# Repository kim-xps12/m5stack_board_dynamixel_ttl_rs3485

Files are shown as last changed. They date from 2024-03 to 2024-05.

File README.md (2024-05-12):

# DYNAMIXEL TTL interface board for M5Stack

## About
M5StackからDYNAMIXEL TTL対応のシリアルサーボを操作するためのオリジナル基板です．KiCAD 7で設計しました．

## Appearance

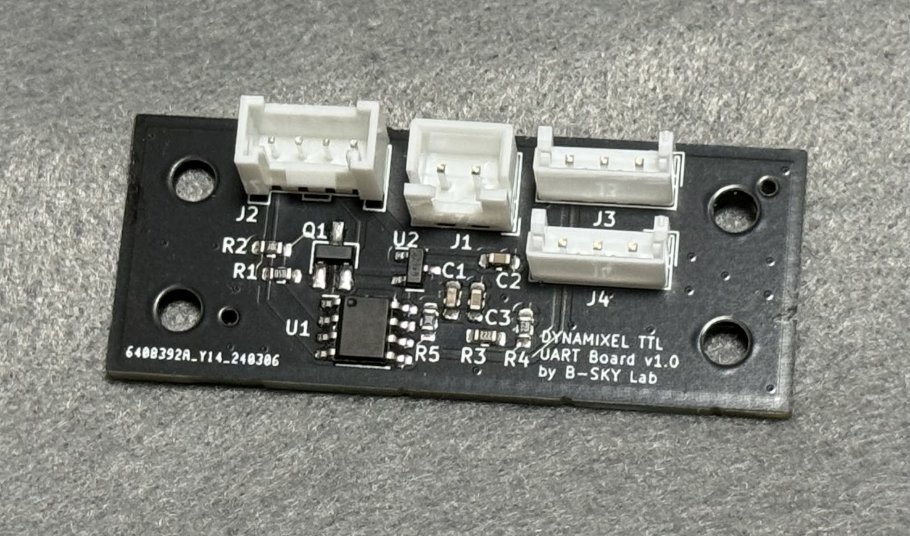
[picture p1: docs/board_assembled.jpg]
assembled board


## Usage

配線と動作の様子はこちら．

https://www.youtube.com/watch?v=RdcbOagrEI8

## Schematics

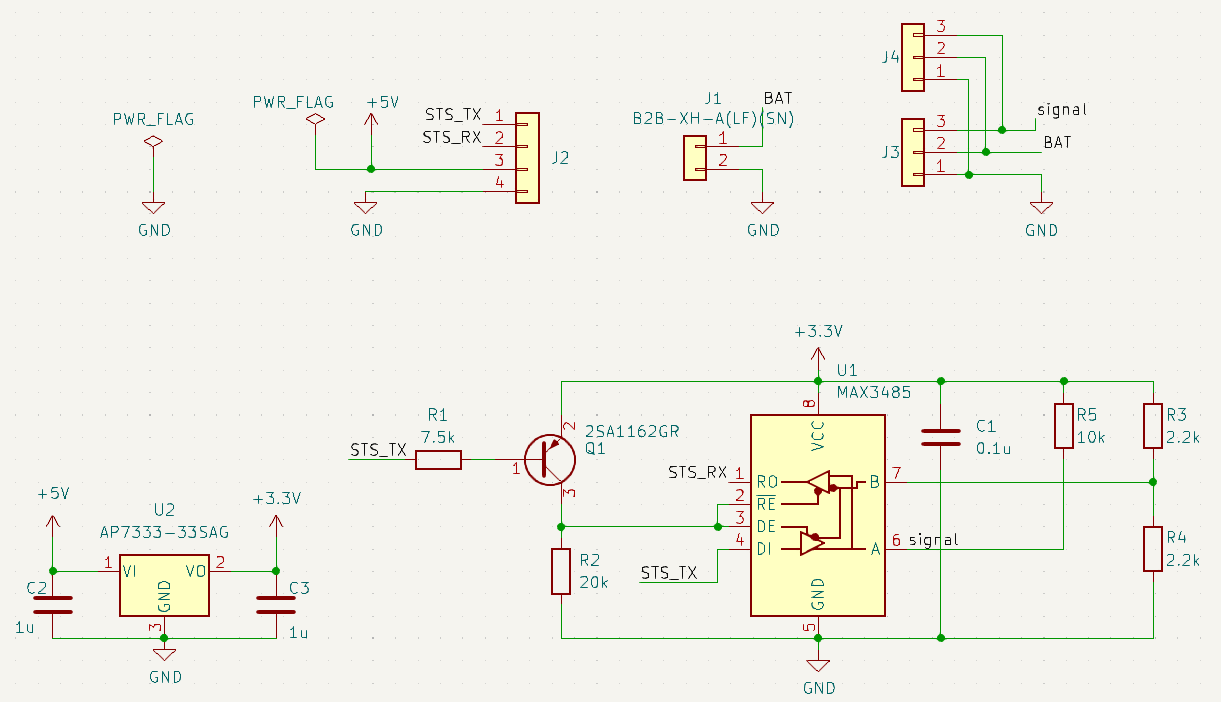
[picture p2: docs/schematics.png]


## Pin assign

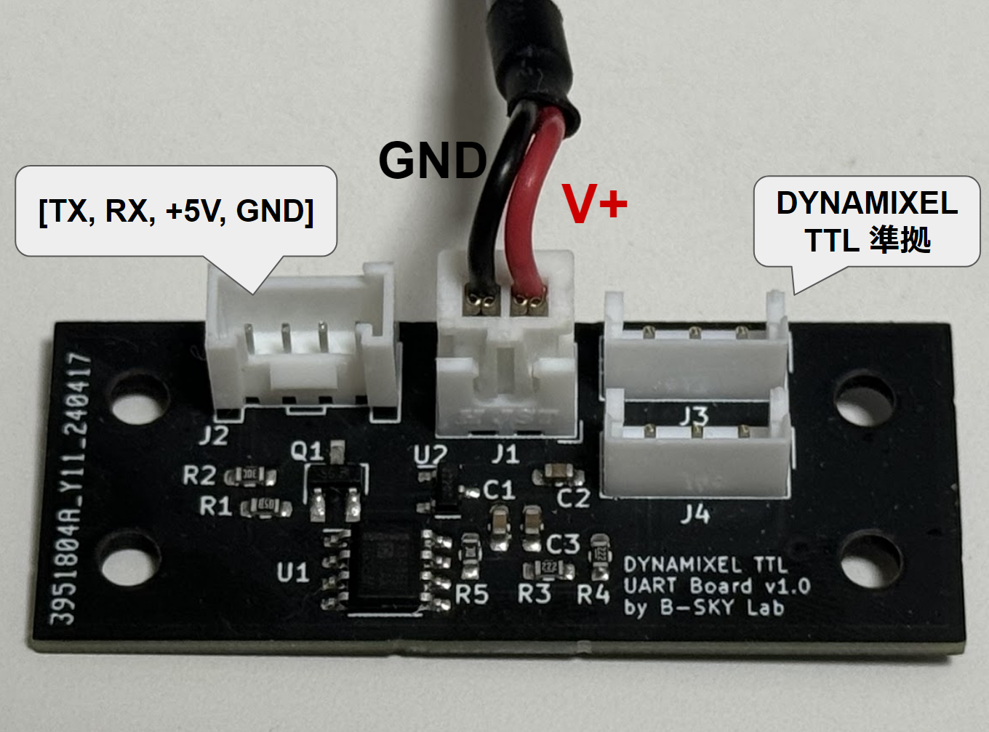
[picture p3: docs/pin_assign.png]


## Layout

unit: millimetre

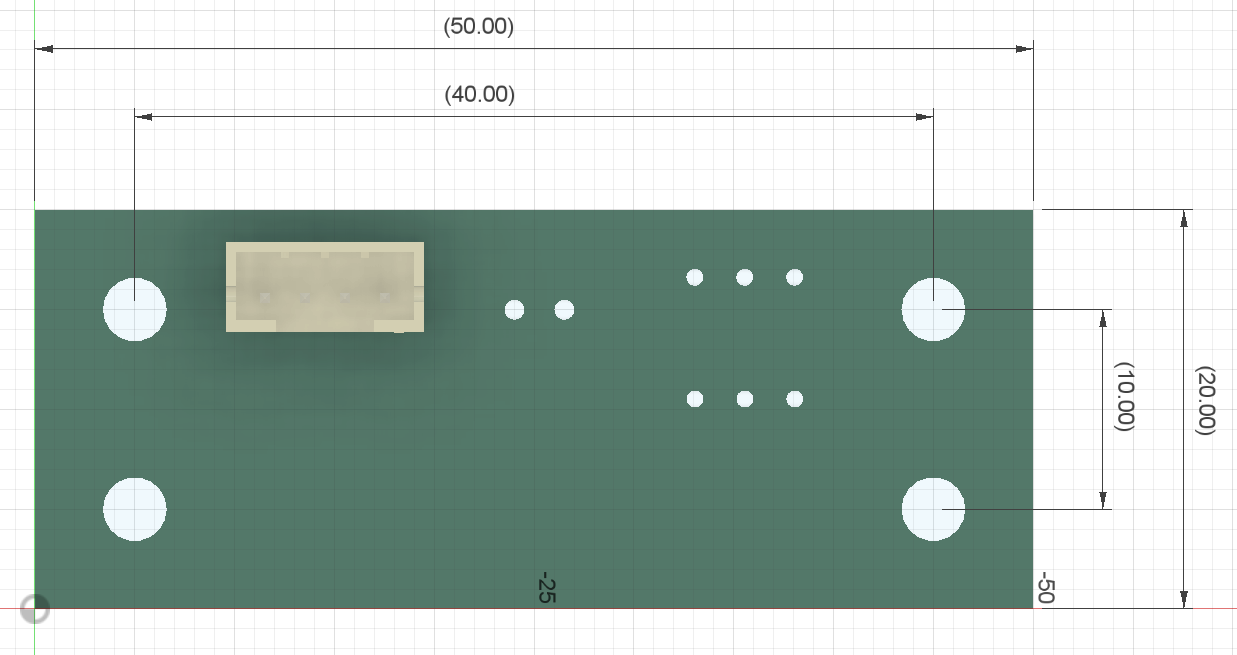
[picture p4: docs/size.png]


## BOM
| Symbol | Model Number |URL, Values|
| --- | --- | --- |
| Q1  | 2SA1162GR<br> | [https://akizukidenshi.com/catalog/g/gI-02702/](https://akizukidenshi.com/catalog/g/gI-02702/)<br> |
| U1  | MAX3485ED<br> | [https://akizukidenshi.com/catalog/g/gI-16211/](https://akizukidenshi.com/catalog/g/gI-16211/)<br> |
| U2  | AP7333<br> | [https://akizukidenshi.com/catalog/g/gI-11360/](https://akizukidenshi.com/catalog/g/gI-11360/)<br> |
| J1  | JST B4B-PH-K-S(LF)(SN) | [https://www.sengoku.co.jp/mod/sgk\_cart/detail.php?code=4DK2-SDDB](https://www.sengoku.co.jp/mod/sgk_cart/detail.php?code=4DK2-SDDB)<br> |
| J2  | HY2.0-4PZZ | [https://ssci.to/1122](https://ssci.to/1122)<br> |
| J3  | B3B-EH(LF)(SN) | [https://www.sengoku.co.jp/mod/sgk_cart/detail.php?code=EEHD-4KBP](https://www.sengoku.co.jp/mod/sgk_cart/detail.php?code=EEHD-4KBP)<br> |
| R | 0608 inch / 1608 jis metric | R1=7.5k, R2=20k, R3=R4=2.2k |
| C | 0608 inch / 1608 jis metric | C1=0.1 u, C2=C3=1u |

## Exammple code

### Arduino IDE

1. Dynamixel2Arduinoライブラリをインストールします．ROBOTIS e-manualを参照してください．
    Install Dynamixel2Arduino library from ROBOTIS e-manual.
   
    ROBOTIS e-manual : [日本語](https://emanual.robotis.com/docs/en/software/arduino_ide_jp/), [English](https://emanual.robotis.com/docs/en/software/arduino_ide/)

3. Arduino IDEで[同封のサンプルコード](example_m5core2_dynamixel_arduino_ide/example_m5core2_dynamixel_arduino_ide.ino)を開いて，M5Stack Core2へ書き込みます．
    Open the enclosed [example code](example_m5core2_dynamixel_arduino_ide/example_m5core2_dynamixel_arduino_ide.ino) with Arduino IDE and write it to M5Stack Core2.

4. [Usage](#usage) の動画を参考に配線して電源を投入してください．
    Please refer to the Usage video to wire and turn on the power.

### PlatformIO

comming soon :)

## NOTE
ご自身の環境で本リポジトリを利用する際は，`HY2.0-4P.kicad_mod` を適切なライブラリへインポートしてお使いください．
作者はグローバルライブラリへインポートして複数プロジェクトから利用できるようにしています．

When using this repository in your own environment, please import HY2.0-4P.kicad_mod into the appropriate library. 
I import it into the global library so that it can be used from other projects as well.

## Distribution
本基板（完成品）はboothで頒布中です．よろしければご利用ください．

[https://b-sky-lab.booth.pm/items/5576375](https://b-sky-lab.booth.pm/items/5576375)

## Disclaimer
MITライセンスでの公開です．本設計および頒布した基板において生じた一切の損害等について作者は責任を負いません．予めご了承ください．

This is released under the MIT license. The author is not responsible for any damage caused to this design or the distributed board. Please note.

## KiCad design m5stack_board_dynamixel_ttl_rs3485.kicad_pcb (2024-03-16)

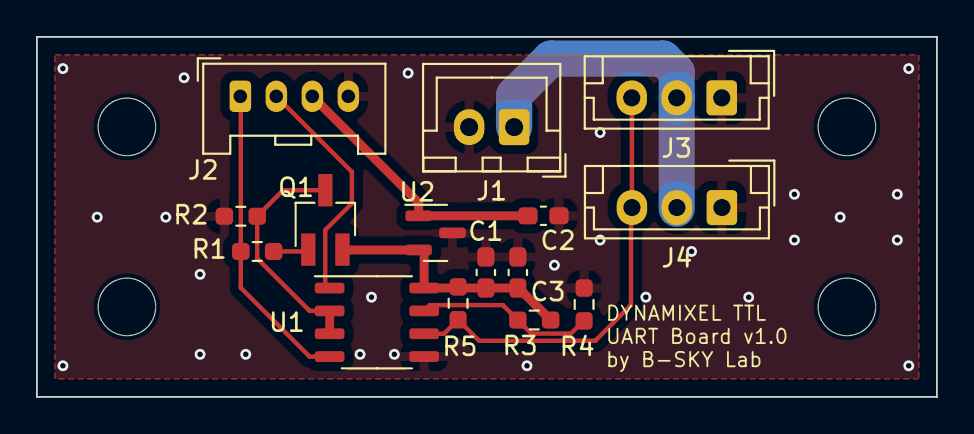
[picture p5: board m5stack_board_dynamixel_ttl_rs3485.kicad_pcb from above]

Board: 2 copper layers, 50.0 x 20.0 mm, 19 parts (0 on the bottom side), 10 nets.

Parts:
C1: 0.1u; C_0603_1608Metric_Pad1.08x0.95mm_HandSolder
C2, C3: 1u; C_0603_1608Metric_Pad1.08x0.95mm_HandSolder
J1: B2B-XH-A(LF)(SN); JST_XH_B2B-XH-A_1x02_P2.50mm_Vertical
J2: WAFER-HY2.0-4PZZ; HY2.0-4P
J3, J4: B3B-EH-A(LF)(SN); JST_EH_B3B-EH-A_1x03_P2.50mm_Vertical
MH1, MH2, MH3, MH4: MountingHole_3.2mm_M3
Q1: 2SA1162GR; SC-59_Handsoldering
R1: 7.5k; R_0603_1608Metric_Pad0.98x0.95mm_HandSolder
R2: 20k; R_0603_1608Metric_Pad0.98x0.95mm_HandSolder
R3, R4: 2.2k; R_0603_1608Metric_Pad0.98x0.95mm_HandSolder
R5: 10k; R_0603_1608Metric_Pad0.98x0.95mm_HandSolder
U1: MAX3485; SOP-8_3.9x4.9mm_P1.27mm
U2: AP7333-33SAG; SOT-23

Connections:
+3.3V: C1.1, C3.1, Q1.2 (E), R3.2, R5.2, U1.8 (VCC), U2.2 (VO)
+5V: C2.1, J2.3, U2.1 (VI)
/BAT: J1.1, J3.2, J4.2
/STS_RX: J2.2, U1.1 (RO)
/STS_TX: J2.1, R1.1, U1.4 (DI)
/signal: J3.3, J4.3, R5.1, U1.6 (A)
GND: C1.2, C2.2, C3.2, J1.2, J2.4, J3.1, J4.1, R2.1, R4.1, U1.5 (GND), U2.3 (GND)
unnamed: Q1.1 (B), R1.2
unnamed: Q1.3 (C), R2.2, U1.2 (~RE), U1.3 (DE)
unnamed: R3.1, R4.2, U1.7 (B)

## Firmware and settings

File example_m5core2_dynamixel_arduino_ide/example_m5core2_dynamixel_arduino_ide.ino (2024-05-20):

#include <Dynamixel2Arduino.h>
#include <M5Unified.h>

#define DEBUG_SERIAL Serial
HardwareSerial& DXL_SERIAL = Serial1;
Dynamixel2Arduino dxl;

// M5Stack Core2 PORT A
const uint8_t RX_SERVO = 32;
const uint8_t TX_SERVO = 33;

const uint8_t DXL_ID = 1;
const float DXL_PROTOCOL_VERSION = 2.0;

using namespace ControlTableItem;

void setup() {

  DXL_SERIAL.begin(57600, SERIAL_8N1, RX_SERVO, TX_SERVO);
  dxl = Dynamixel2Arduino(DXL_SERIAL);

  M5.begin();
  M5.Lcd.setTextSize(2);
  M5.Display.println("DYNAMIXEL TTL");
  M5.Display.println("");
  M5.Display.println("Velocity Mode Example");
  M5.Display.println("");
  M5.Display.println("Initializing...");
  DEBUG_SERIAL.begin(115200);

  dxl.begin(57600);
  dxl.setPortProtocolVersion(DXL_PROTOCOL_VERSION);
  dxl.ping(DXL_ID);

  dxl.torqueOff(DXL_ID);
  dxl.setOperatingMode(DXL_ID, OP_VELOCITY);
  dxl.torqueOn(DXL_ID);
}


void loop() {

  // Reset display
  M5.Display.clear();
  M5.Display.setCursor(0, 0);

  // Set Goal Velocity using RPM
  dxl.setGoalVelocity(DXL_ID, 60, UNIT_RPM);
  delay(1000);

  int rpm = dxl.getPresentVelocity(DXL_ID, UNIT_RPM);

  DEBUG_SERIAL.print("Target Velocity(rpm): 60");
  DEBUG_SERIAL.print("Present Velocity(rpm) : ");
  DEBUG_SERIAL.println(rpm);
  M5.Display.println("DYNAMIXEL TTL");
  M5.Display.println("Target Velocity(rpm): 60");
  M5.Display.print("Present Velocity(rpm) : ");
  M5.Display.println(rpm);
  M5.Display.println("");
  delay(1000);

  dxl.setGoalVelocity(DXL_ID, -60, UNIT_RPM);
  delay(1000);

  rpm = dxl.getPresentVelocity(DXL_ID, UNIT_RPM);
  DEBUG_SERIAL.println("Target Velocity(rpm): -60");
  DEBUG_SERIAL.print("Present Velocity(rpm): ");
  DEBUG_SERIAL.println(rpm);

  M5.Display.println("DYNAMIXEL TTL");
  M5.Display.println("Target Velocity(rpm): -60");
  M5.Display.print("Present Velocity(rpm): ");
  M5.Display.println(rpm);
  M5.Display.println("");
  delay(1000);
}

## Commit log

2024-05-12 update README (add pin assign and layout)
2024-05-20 print servo status (rpm) on M5 display
2024-09-20 update board
2024-09-20 update example, fix pin assign for based on PORT.C UART
2026-10-11 docs: update images for board v2 and archive v1 images (#4)
    - Update board_assembled.jpg, pin_assign.png, schematics.png to board v2
    - Keep previous v1 images as *_v1 for reference
